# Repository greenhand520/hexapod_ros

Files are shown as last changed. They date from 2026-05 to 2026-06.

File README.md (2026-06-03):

<h1 align="center">Hexapod-ROS</h1>

<p align="center">
  <strong>一个基于 ROS2 的开源六足机器人平台，支持实时步态控制、激光雷达导航</strong>
</p>
<p align="center">
  <a href="#简介">简介</a> •
  <a href="#快速开始">快速开始</a> •
  <a href="#硬件">硬件</a> •
  <a href="#软件">软件</a> •
  <a href="#参与贡献">参与贡献</a> •
  <a href="#开源许可">开源许可</a> •
  <a href="#致谢">致谢</a>
</p>

---

## 简介

### 项目概述

Hexapod-ROS 是一个开源的六足机器人平台（目前正在利用业余时间开发中）。机器人采用双处理器架构——**鲁班猫 Zero (RK3566)** 运行 ROS2 Humble，负责高层感知、路径规划与运动控制；**STM32F405RGT6** 运行 FreeRTOS 与 MicroROS，负责实时发布 IMU 数据、充电控制、温度监控、发布电池等硬件信息。由鲁班猫直接控制的18个舵机使用的是 UBTECH 的拆机舵机，舵机详情可参考“[某宝白菜价舵机](https://gitee.com/alicedodo/xaobao_cheap_bus_servo_hack_record/)”。

**主要功能包括：**

- 18 自由度运动控制，支持逆运动学解算与多种步态模式
- 基于 360° 二维激光雷达的 SLAM 建图与自主导航（Navigation2）
- 实时 IMU 姿态估计与电池管理

<p align="center">
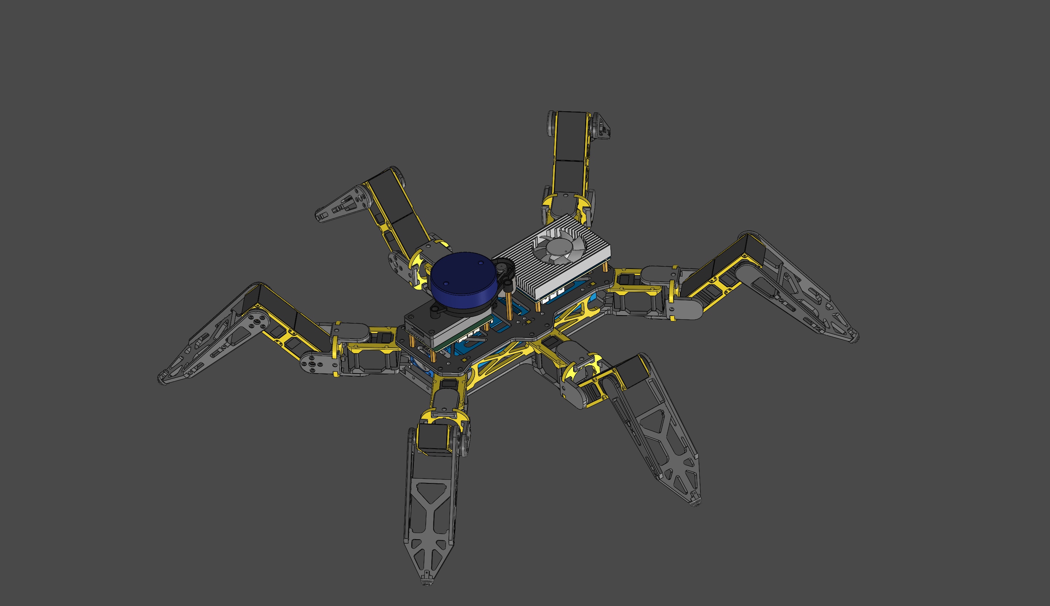
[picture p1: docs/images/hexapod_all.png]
整体结构
  
</p>

### 系统架构

系统分为三个层次：**软件层**、**硬件层**和**电源层**。以下架构图提供了完整的系统总览。

#### 硬件架构

<p align="center">
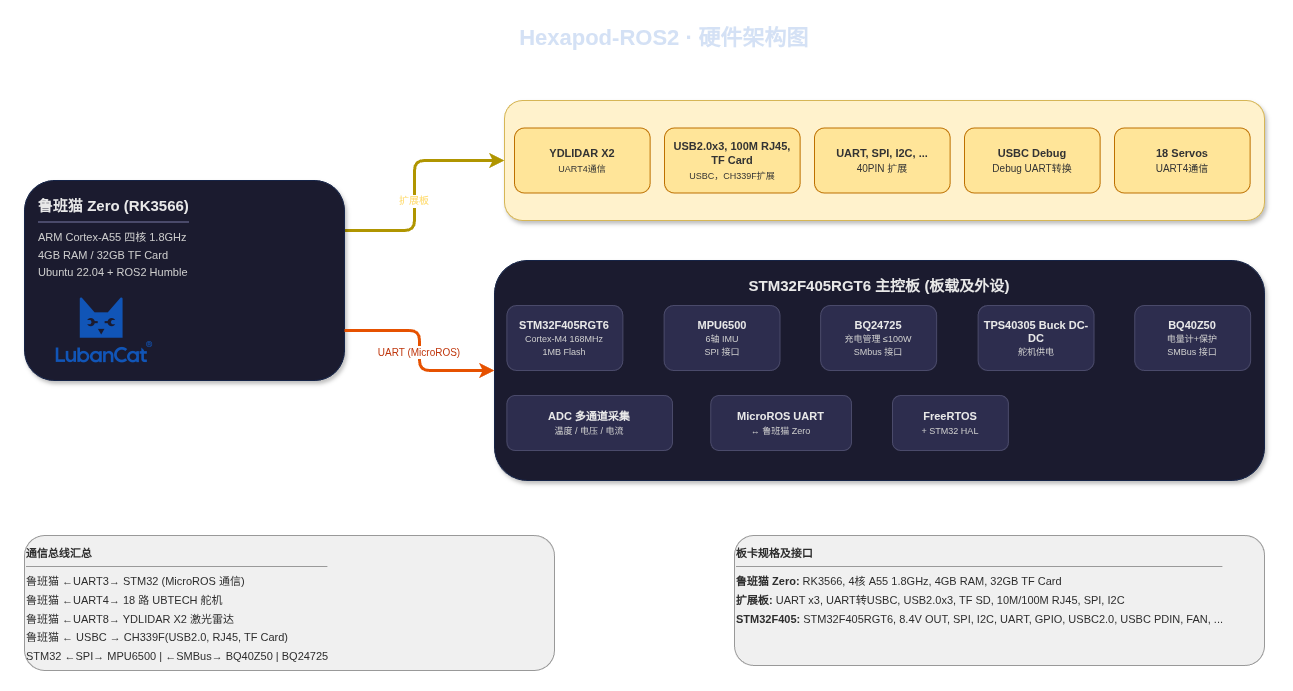
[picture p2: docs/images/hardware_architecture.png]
硬件架构图
  
</p>

> 架构图源文件位于 [`docs/diagrams/hardware_architecture.drawio`](docs/diagrams/hardware_architecture.drawio)。

#### 软件架构

TODO: 等待全部开发完毕

#### 电源架构

<p align="center">
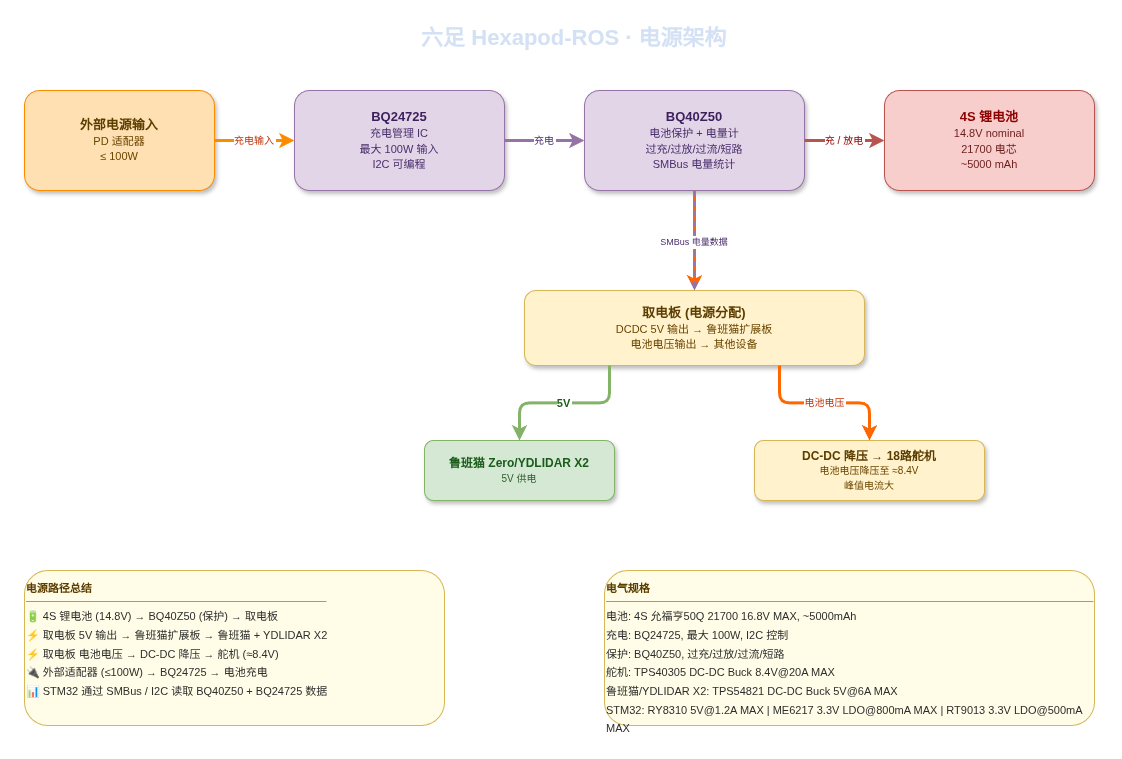
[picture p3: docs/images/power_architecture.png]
电源架构图
  
</p>

> 架构图源文件位于 [`docs/diagrams/power_architecture.drawio`](docs/diagrams/power_architecture.drawio)。

---

## 快速开始

### 环境依赖

| 组件 | 要求 |
| --- | --- |
| **操作系统（鲁班猫/开发机）** | Ubuntu 22.04 LTS |
| **开发环境** | ROS2 Humble、MicroROS for STM32、Python3.10、gcc-13、CLion、STM32CubeMX |
| **仿真环境** | Gazebo 11 |
| **3D 打印** | Bambu Lab A1、PETG 耗材（已测试） |

### 编译项目

**1. 克隆仓库**

```bash
git https://github.com/greenhand520/hexapod_ros.git
cd hexapod_ros
git submodule init   
git submodule update --remote --checkout
```

**2. 安装需要的软件包**

```bash
# YDLIDAR SDK
git clone https://github.com/YDLIDAR/YDLidar-SDK.git
cd YDLidar-SDK
mkdir build
cd build
cmake ..
make
sudo make install

# microros agent
cd software/hexapod_ros_ws/
chmod +x ./install_microros_agent.sh
./install_microros_agent.sh
```

**3. 编译 ROS2 工作空间**

```bash
cd software/hexapod_ros_ws/
rosdep install --from-paths src --ignore-src -r -y
chmod +x ./colcon_build.sh
./colcon_build.sh
source install/setup.bash
# 启动
ros2 launch hexapod_bringup start.launch.py
# 添加自启动服务
TODO
```

**4. 编译并烧录 STM32 固件**

```bash
cd software/hexapod_ros_ws/
chmod +x lib_microros_generation.sh
# 编译 microros 静态库并将相关文件复制到 hexapod_stm32f405 中
./lib_microros_generation.sh -r
```

在 Clion 中打开 `software/hexapod_stm32f405/`，编译项目后通过 ST-Link 烧录。

## 硬件

### 主控板

| 组件 | 规格 |
| --- | --- |
| **鲁班猫 Zero** | RK3566，ARM Cortex-A55 四核 1.8GHz，4GB RAM，32GB TF Card |
| **鲁班猫 Zero 扩展板** | UART ×3、UART 转 USB-C、USB2.0 ×3、TF SD、10M/100M RJ45、SPI、I2C、etc... |
| **STM32F405RGT6** | Cortex-M4 168MHz，1MB Flash，192KB SRAM，SPI、I2C、UART、GPIO、USB-C 2.0、USB-C PD 输入 |

### 外设与传感器

| 组件 | 描述 | 接口  |
| --- | --- | ----- |
| **UBTECH 舵机** ×18 | 6 条腿 × 3 关节，串口总线舵机 | UART4 |
| **YDLIDAR X2** | 二维360° 激光雷达 | UART8 |
| **MPU6500** | 6 轴 IMU（加速度计 + 陀螺仪） | SPI |
| **BQ40Z50** | 电池电量计 + 保护（过充/过放/过流/短路） | SMBus |
| **BQ24725** | 电池充电管理 IC，最大 100W 输入 | SMBus |
| **CH339F** | USB 2.0 Hub + 以太网 + TF Card 扩展 | USB-C |

### 电源系统

| 参数 | 值 |
| --- | --- |
| **电池** | 4S 锂电池（标称 14.8V），约 5000mAh，21700 电芯 |
| **充电** | BQ24725，最大 100W，SMBus 可编程 |
| **保护** | BQ40Z50，过充/过放/过流/短路保护 |
| **舵机供电** | TPS40305 Buck DC-DC，电池电压降压至约 8.4V |
| **鲁班猫供电** | 取电板 5V 输出 |
| **STM32 供电** | 3.3V LDO |

### PCB 设计

所有PCB（主控板、扩展板、取电板、电池保护版）均使用 [JLCEDA Pro](https://pro.lceda.cn/editor/) 进行设计，对应工程文件位于 [`hardware`](hardware/) 目录下。

> 最新可以直接在线查看的 PCB 项目文件可以访问 [oshwhub 发布页面](https://oshwhub.com/) （等待所有PCB测试通过）。

### 3D 打印与机械结构

机身设计参考经典 [hexapod 项目](https://github.com/SmallpTsai/hexapod-v2-7697)的结构，在参考 STL 文件后为了适配 UBTECH 舵机和 4S 21700 电池，进行了完全的重建。采用 3D 打印完成，建模参数适应 **PETG 材料** 和 **Bambu Lab A1** 打印机。其他材料和打印机未经测试，结构强度和尺寸无法保证。打印文件和物料清单（BOM）位于 [`mechanism`](mechanism/) 目录下：

```
mechanism/
├── stl/                    # 最新可打印 STL 文件
├── step/                   # STEP 文件用于生成 urdf
├── BOM.md                  # 物料清单（紧固件、轴承等）(TODO)
└── assembly_guide.md       # 装配指南(TODO)
```

> 最新打印文件访问 [Makeword 发布页面](https://makerworld.com.cn/zh)（稍后开放）。

---

##  软件

软件分为两个主要部分：**STM32 固件** 负责实时硬件驱动，**ROS2 工作空间** 运行在鲁班猫上，负责感知、规划与控制。

### STM32 固件 (`software/hexapod_stm32f405/`)

STM32 固件基于 FreeRTOS 和 STM32 HAL 库运行，通过 MicroROS 经 UART 与鲁班猫通信。

**主要职责：**

- 发布 MPU6500 的 IMU 数据（`/imu/data` 话题）
- 发布 BQ40Z50 的电池状态（`/battery/status` 话题）
- 通过 ADC 采集并发布板载温度、电压数据和BQ24725 的充电状态（`/sensor/board_state` 话题）

### ROS2 工作空间 (`software/hexapod_ros_ws/`)

ROS2 工作空间包含运行在鲁班猫 Zero（RK3566）上的所有高层功能包，系统为 Ubuntu 22.04 + ROS2 Humble。

```
software/hexapod_ros_ws/
├── src
│   ├── hexapod_bringup
│   ├── hexapod_description
│   ├── hexapod_interface
│   ├── hexapod_sensor_interface
│   ├── hexapod_test_ubtech_servo
│   ├── hexapod_test_ubtech_servo_interface
│   ├── hexapod_ubtech_ros2_control
│   └── ydlidar_ros2_driver
├── CMakeLists.txt
├── colcon_build.sh
├── env.sh
└── generate_and_deploy_microros.sh
```

#### 功能包说明

| 功能包 | 描述 |
| --- | --- |
| hexapod_bringup | 系统启动的 Launch 文件和配置。按正确顺序启动所有硬件驱动、`ros2_control` 控制器、传感器节点和 MicroROS Agent。另外包含见图、当航、IMU融合的配置和启动文件 |
| hexapod_description | RDF/Xacro 机器人模型、网格文件、TF 坐标系与 RViz 可视化配置。定义了 18 自由度运动学结构 |
| hexapod_interface | 定义了hexapod 各节点通信的 msg/service/action 文件 |
| hexapod_sensor_interface | 定义了与 stm32 通信的 msg 文件 |
| hexapod_test_ubtech_servo | 测试使用 ros2_control 控制 ubtech 舵机是否正常工作的节点 |
| hexapod_test_ubtech_servo_interface | 定义测试 ubtech 舵机服务使用的 service 文件 |
| hexapod_ubtech_ros2_control | 使用 ros2_control 控制 ubtech 舵机，后续可更换成其他舵机，只要实现对应舵机的 ros2_control功能包即可 |
| ydlidar_ros2_driver | YDLIDAR X2 激光雷达 ROS2 驱动 |
| hexapod_controller | 将速度/朝向指令转成足端轨迹/每条腿的foot trajectory，将足端轨迹 (x,y,z) 转成18个关节的舵机转动角度 |

---

## 开发进度与路线

- [x] 硬件设计（PCB、原理图）
- [x] 3D 打印机身设计（PETG、Bambu Lab A1）
- [x] 基础 ROS2 bringup 与 ros2_control
- [x] STM32 固件与 MicroROS 集成
- [x] 逆运动学解算与三角步态
- [x] YDLIDAR X2 驱动与 SLAM 集成
- [x] Navigation2 路径规划
- [ ] RL 训练环境（Gazebo + PyBullet）
- [ ] RL 运动策略训练（PPO / SAC）
- [ ] 仿真到实物策略部署
- [ ] 多步态 RL 切换（三角步态、涟漪步态、波浪步态）
- [ ] RL + Nav2 联合自主探索
- [ ] 文档与装配视频教程

---

## 参与贡献

欢迎参与贡献！请阅读以下指南：

TODO

---

## 开源许可

本项目基于 **GNU 通用公共许可证 v3.0** 开源——详见 [LICENSE](LICENSE) 文件。

硬件设计（PCB 原理图、3D 模型）基于 **CERN 开放硬件许可 v2（CERN-OHL-P-2.0）** 开源。

---

## 致谢

排名不分先后

- [ROS2](https://docs.ros.org/) — 机器人操作系统 2
- [Xiaomi MiMo Token Plan](https://platform.xiaomimimo.com/token-plan) — 小米 MiMo 大模型 Token 订阅计划
- [CLion](https://www.jetbrains.com/clion/) — 为顺畅工作流程和高效开发而设计的跨平台 C/C++ 集成开发环境
- [MicroROS](https://micro.ros.org/) — 面向微控制器的 ROS2
- [Navigation2](https://nav2.org//) — ROS2 导航框架
- [YDLIDAR](https://www.ydlidar.com/) — 激光雷达 SDK
- [鲁班猫](https://doc.embedfire.com/linux/rk356x/quick_start/zh/latest/quick_start/lubancat/lubancat.html) — 鲁班猫 Zero 单板计算机
- [JLCEDA](https://lceda.cn/) — PCB 设计工具（立创 EDA）
- [Bambu Lab](https://bambulab.com/) — 3D 打印平台

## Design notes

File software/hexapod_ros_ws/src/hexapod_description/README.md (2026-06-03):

## 新建Markdown

```xml
<joint name="coxa_L1" type="revolute">
  <limit lower="-1.047" upper="1.047" />  <!-- ±60° -->
</joint>

<joint name="femur_L1" type="revolute">
  <limit lower="-1.57" upper="0.52" />  <!-- 向下最多90°, 向上30° -->
</joint>

<joint name="tibia_L1" type="revolute">
  <limit lower="-0.52" upper="2.09" />  <!-- 弯曲范围 -->
</joint>

```

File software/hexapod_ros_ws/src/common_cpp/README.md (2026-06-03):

common_cpp

公共的日志记录，使用 spdlog 代替 rclcpp 的后端日志实现，并且支持自定义日志实现

## 使用方法

### CMakeLists配置

```cmake
find_package(common_cpp REQUIRED)

if (DEFINED ENV{CLION_IDE})
    target_link_libraries(${PROJECT_NAME} PUBLIC
            common_cpp
    )
else ()
    ament_target_dependencies(${PROJECT_NAME} PUBLIC
            common_cpp
    )
endif ()
```

### 初始化

方式1：当模块可以获取到 ros2 节点 node 实例时，可以在在 main 函数中按照下面顺序初始化全局日志

```cpp
#include "common_cpp/rclcpp_log_handler.hpp"
#include "common_cpp/spdlog_adapter.hpp"
#include "common_cpp/log_interface/log_manager.hpp"

const auto node = std::make_shared<rclcpp::Node>("log_test_node");
// 1、先使用RclcppLogHandler初始化日志logger
common_log::RclcppLogHandler::init_from_node(node);
// 2、获取刚才创建的logger实例中得到spdlogger对象
const auto logger = common_log::Logger::get_instance().get_logger();
// 3、创建一个适配spdlog的log_interface对象
const auto logger_interface = common_log::SpdlogLoggerAdapter::create_spdlog_logger(logger);
// 4、设置全局日志 这样就统一log_macro.hpp和RCLCPP_xxx()的日志记录结果了
log_interface::LogManager::set(logger_interface);
```

方式2：获取不到 node 实例时，可以按照下面顺序初始化日志

```cpp
// 还是先使用RclcppLogHandler初始化日志logger
// 假设params是你存储配置的map,map的key和yaml中定义的一样
std::unordered_map<std::string, std::string> params;
common_log::RclcppLogHandler::init_from_map(params);
// 或者自己实现获取LogConfig
LogConfig log_config;
common_log::RclcppLogHandler::init_from_config(log_config);
// 后续操作和前面一样
const auto logger = common_log::Logger::get_instance().get_logger();
const auto logger_interface = common_log::SpdlogLoggerAdapter::create_spdlog_logger(logger);
log_interface::LogManager::set(logger_interface);
```

方式3：如果不想代替 RCLCPP 的后端来记录日志，不调用`RclcppLogHandler`的几个`init_from_xxx`函数即可。

```cpp
// 先创建LogConfig，它的配置内容获取可以自己实现
common_log::LogConfig log_config;
// 这里提供了一个默认实现，假设params是你存储配置的map
std::unordered_map<std::string, std::string> params;
log_config.init_from_map(params);
// 初始化日志logger
common_log::Logger::init_from_config(&log_config);
// 后续操作和前面一样
const auto logger = common_log::Logger::get_instance().get_logger();
const auto logger_interface = common_log::SpdlogLoggerAdapter::create_spdlog_logger(logger);
log_interface::LogManager::set(logger_interface);
```

> 调用`RclcppLogHandler`中的几个`init_from_xxx`后 RCLCPP 记录日志的后端才会用这个 common_cpp 来实现，而具体的实现依靠`log_interface::LogManager::set(logger_interface);`

### 记录日志

1、ros2相关代码中正常使用

```cpp
    RCLCPP_DEBUG(node->get_logger(), "debug log test: ctcemti_log_test_node started");
    RCLCPP_INFO(node->get_logger(), "info log test: ctcemti_log_test_node started");
    RCLCPP_WARN(node->get_logger(), "warn log test: ctcemti_log_test_node started");
    RCLCPP_ERROR(node->get_logger(), "error log test: ctcemti_log_test_node started");
    RCLCPP_FATAL(node->get_logger(), "fatal log test: ctcemti_log_test_node started");
```

2、使用`log_interface/log_macro.hpp`中的宏

```cpp
LOG_DEBUG("test_log_debug {}", 123);
LOG_INFO("test_log_info {}", 123);
LOG_INFO("Joint '{}' (ID {}): initial {:.1f}° → {:.4f} rad", jd.name, jd.servo_id, sa.actual_deg, pos);
LOG_WARN("test_log_warn {}", 123);
LOG_ERROR("test_log_error {}", 123);
LOG_FATAL("test_log_fatal {}", 123);
```

### 参数配置

`common_log::RclcppLogHandler::init_from_node(node);`会从 node 的参数中获取一些日志相关的配置，如下：

```yaml
log:
    # 日志登记
    log_level: debug
    # 日志路径
    log_path: ./log
    # 是否是异步日志
    async: false
    # 日志器名字，会影响最终日志文件的名字，不设置的话默认使用节点名
    logger_nama: test
```

上面配置最终会产生日志的路径是`./log/log_test.log`

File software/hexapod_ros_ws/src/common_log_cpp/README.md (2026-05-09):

common_log_cpp

公共的日志记录，使用 spdlog 代替 rclcpp 的后端日志实现，并且支持自定义日志实现

## 使用方法

### CMakeLists配置

```cmake
find_package(common_log_cpp REQUIRED)

if (DEFINED ENV{CLION_IDE})
    target_link_libraries(${PROJECT_NAME} PUBLIC
            common_log_cpp
    )
else ()
    ament_target_dependencies(${PROJECT_NAME} PUBLIC
            common_log_cpp
    )
endif ()
```

### 初始化

方式1：当模块可以获取到 ros2 节点 node 实例时，可以在在 main 函数中按照下面顺序初始化全局日志

```cpp
#include "common_log_cpp/rclcpp_log_handler.hpp"
#include "common_log_cpp/spdlog_adapter.hpp"
#include "common_log_cpp/log_interface/log_manager.hpp"

const auto node = std::make_shared<rclcpp::Node>("log_test_node");
// 1、先使用RclcppLogHandler初始化日志logger
common_log::RclcppLogHandler::init_from_node(node);
// 2、获取刚才创建的logger实例中得到spdlogger对象
const auto logger = common_log::Logger::get_instance().get_logger();
// 3、创建一个适配spdlog的log_interface对象
const auto logger_interface = common_log::SpdlogLoggerAdapter::create_spdlog_logger(logger);
// 4、设置全局日志 这样就统一log_macro.hpp和RCLCPP_xxx()的日志记录结果了
log_interface::LogManager::set(logger_interface);
```

方式2：获取不到 node 实例时，可以按照下面顺序初始化日志

```cpp
// 还是先使用RclcppLogHandler初始化日志logger
// 假设params是你存储配置的map,map的key和yaml中定义的一样
std::unordered_map<std::string, std::string> params;
common_log::RclcppLogHandler::init_from_map(params);
// 或者自己实现获取LogConfig
LogConfig log_config;
common_log::RclcppLogHandler::init_from_config(log_config);
// 后续操作和前面一样
const auto logger = common_log::Logger::get_instance().get_logger();
const auto logger_interface = common_log::SpdlogLoggerAdapter::create_spdlog_logger(logger);
log_interface::LogManager::set(logger_interface);
```

方式3：如果不想代替 RCLCPP 的后端来记录日志，不调用`RclcppLogHandler`的几个`init_from_xxx`函数即可。

```cpp
// 先创建LogConfig，它的配置内容获取可以自己实现
common_log::LogConfig log_config;
// 这里提供了一个默认实现，假设params是你存储配置的map
std::unordered_map<std::string, std::string> params;
log_config.init_from_map(params);
// 初始化日志logger
common_log::Logger::init_from_config(&log_config);
// 后续操作和前面一样
const auto logger = common_log::Logger::get_instance().get_logger();
const auto logger_interface = common_log::SpdlogLoggerAdapter::create_spdlog_logger(logger);
log_interface::LogManager::set(logger_interface);
```

> 调用`RclcppLogHandler`中的几个`init_from_xxx`后 RCLCPP 记录日志的后端才会用这个 common_log_cpp 来实现，而具体的实现依靠`log_interface::LogManager::set(logger_interface);`

### 记录日志

1、ros2相关代码中正常使用

```cpp
    RCLCPP_DEBUG(node->get_logger(), "debug log test: ctcemti_log_test_node started");
    RCLCPP_INFO(node->get_logger(), "info log test: ctcemti_log_test_node started");
    RCLCPP_WARN(node->get_logger(), "warn log test: ctcemti_log_test_node started");
    RCLCPP_ERROR(node->get_logger(), "error log test: ctcemti_log_test_node started");
    RCLCPP_FATAL(node->get_logger(), "fatal log test: ctcemti_log_test_node started");
```

2、使用`log_interface/log_macro.hpp`中的宏

```cpp
LOG_DEBUG("test_log_debug {}", 123);
LOG_INFO("test_log_info {}", 123);
LOG_INFO("Joint '{}' (ID {}): initial {:.1f}° → {:.4f} rad", jd.name, jd.servo_id, sa.actual_deg, pos);
LOG_WARN("test_log_warn {}", 123);
LOG_ERROR("test_log_error {}", 123);
LOG_FATAL("test_log_fatal {}", 123);
```

### 参数配置

`common_log::RclcppLogHandler::init_from_node(node);`会从 node 的参数中获取一些日志相关的配置，如下：

```yaml
log:
    # 日志登记
    log_level: debug
    # 日志路径
    log_path: ./log
    # 是否是异步日志
    async: false
    # 日志器名字，会影响最终日志文件的名字，不设置的话默认使用节点名
    logger_nama: test
```

上面配置最终会产生日志的路径是`./log/log_test.log`

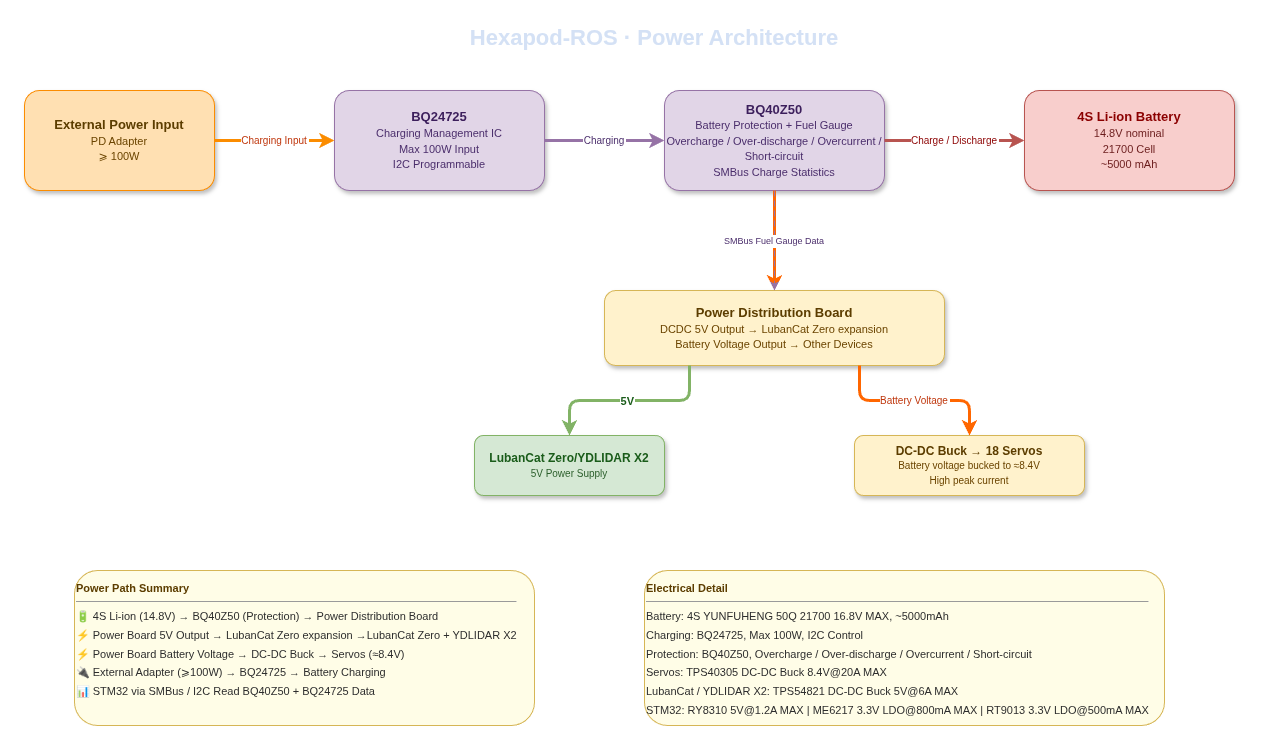
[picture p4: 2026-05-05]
docs/images/power_architecture_en.png

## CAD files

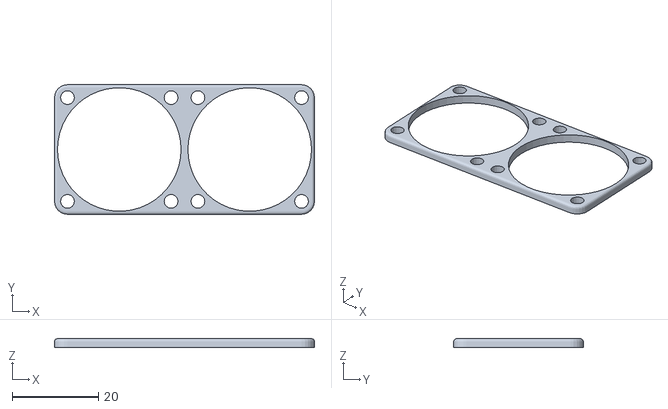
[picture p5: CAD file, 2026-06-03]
mechanism/stl/3010_fan_bracket_full.stl
60.2 x 30.0 x 2.00

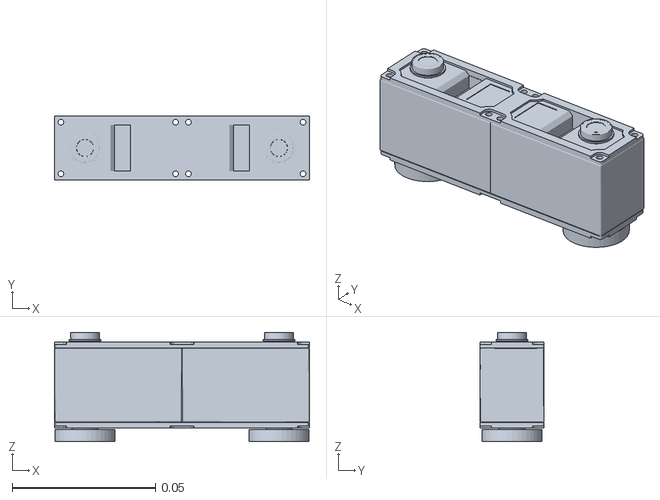
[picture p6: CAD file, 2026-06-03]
software/hexapod_ros_ws/src/hexapod_description/meshes/femur1_link.STL
0.089 x 0.0225 x 0.0381

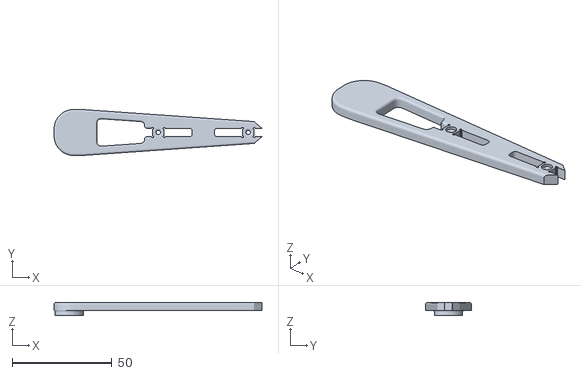
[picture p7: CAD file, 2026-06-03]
mechanism/stl/tibia_bearing.stl
104.5 x 23.2 x 6.60

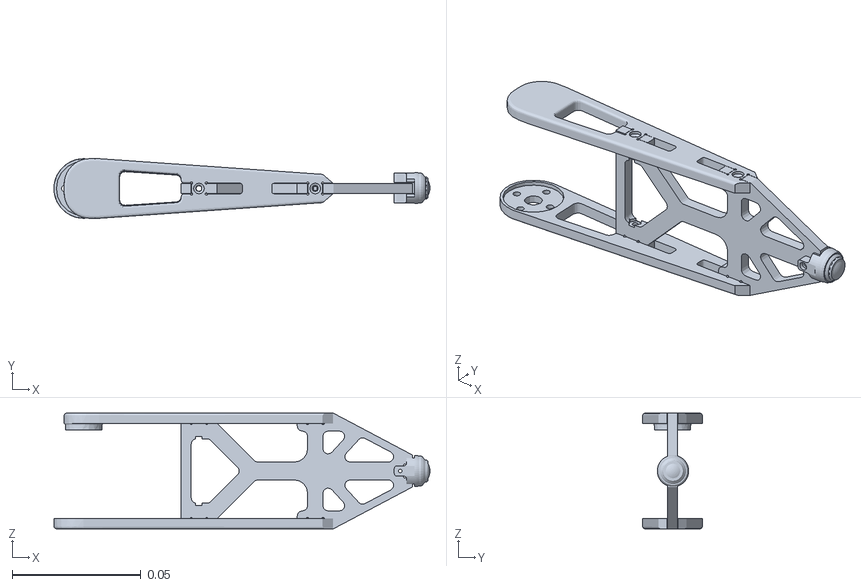
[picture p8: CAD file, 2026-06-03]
software/hexapod_ros_ws/src/hexapod_description/meshes/tibia3_link.STL
0.146 x 0.0232 x 0.045

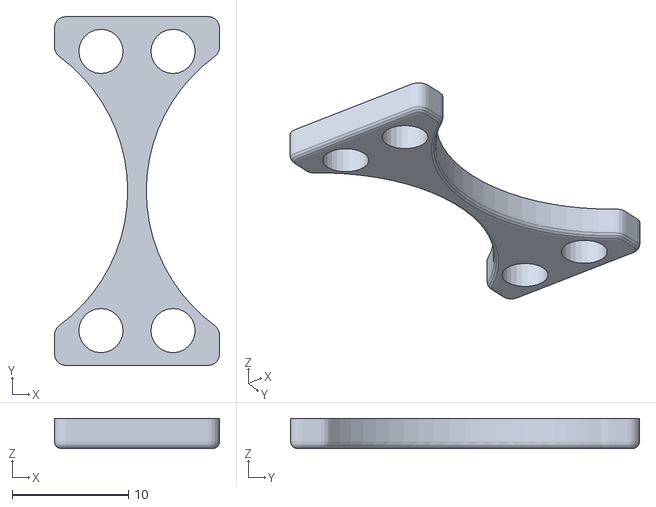
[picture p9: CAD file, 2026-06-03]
mechanism/stl/3010_fan_bracket.stl
14.2 x 30.0 x 2.60

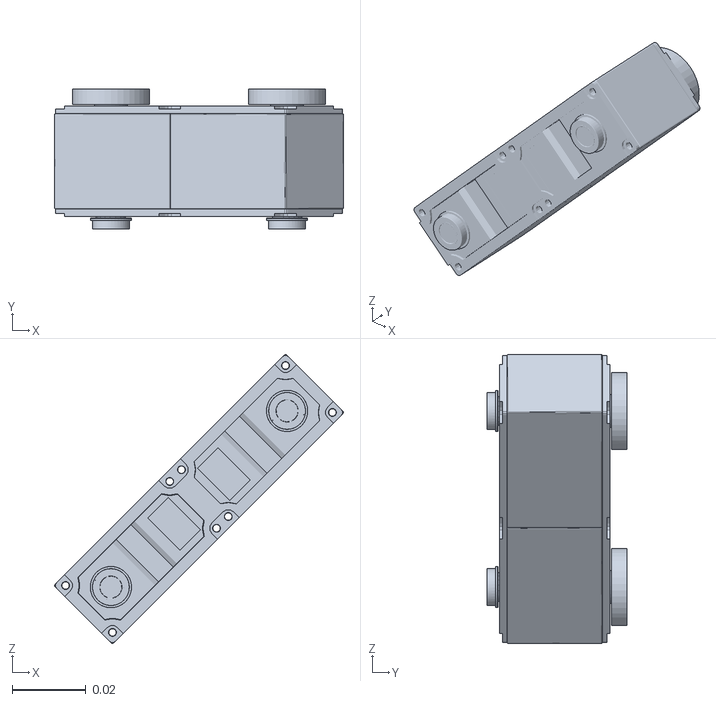
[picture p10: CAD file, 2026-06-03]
software/hexapod_ros_ws/src/hexapod_description/meshes/femur5_link.STL
0.0785 x 0.0381 x 0.0785

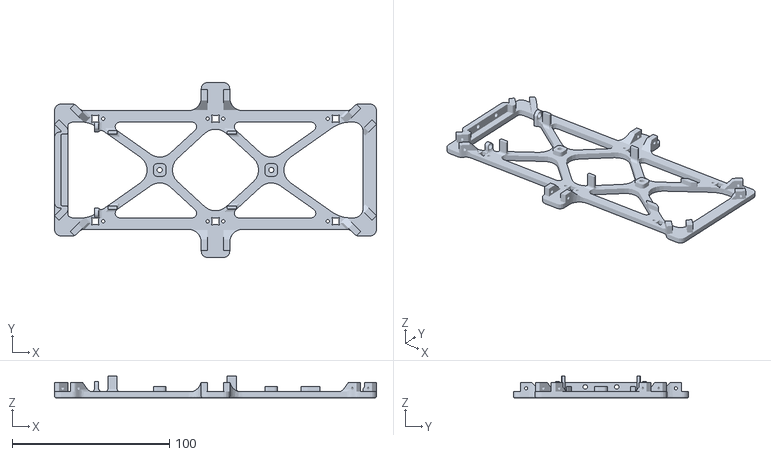
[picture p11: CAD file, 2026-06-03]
mechanism/stl/body_bottom.stl
205.0 x 111.5 x 14.0

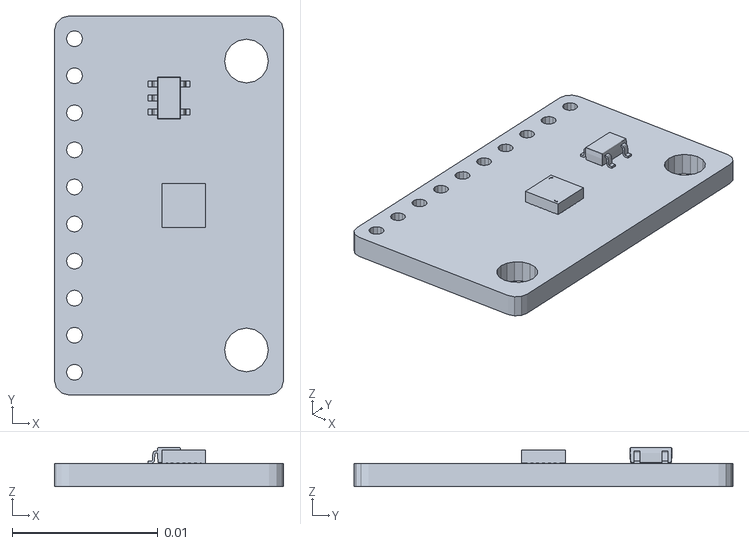
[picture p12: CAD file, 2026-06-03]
software/hexapod_ros_ws/src/hexapod_description/meshes/imu_link.STL
0.0157 x 0.026 x 0.0027

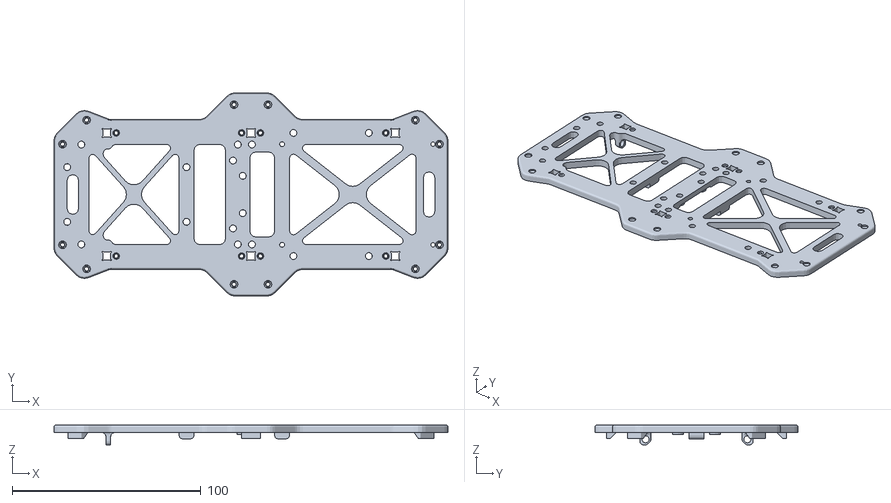
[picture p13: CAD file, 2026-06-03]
mechanism/stl/body_top.stl
209.0 x 107.7 x 10.6

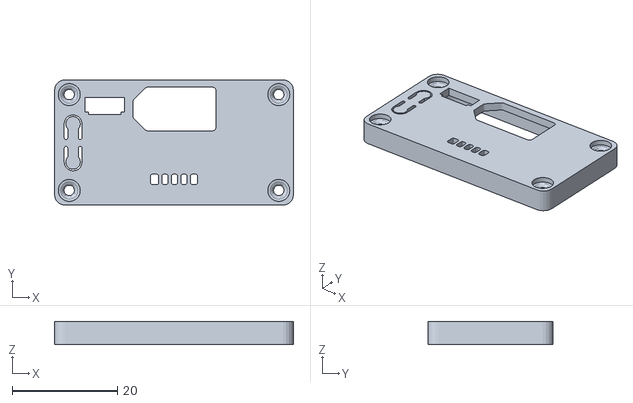
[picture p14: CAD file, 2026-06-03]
mechanism/stl/BZ40Z50_cover.stl
45.4 x 23.8 x 4.40

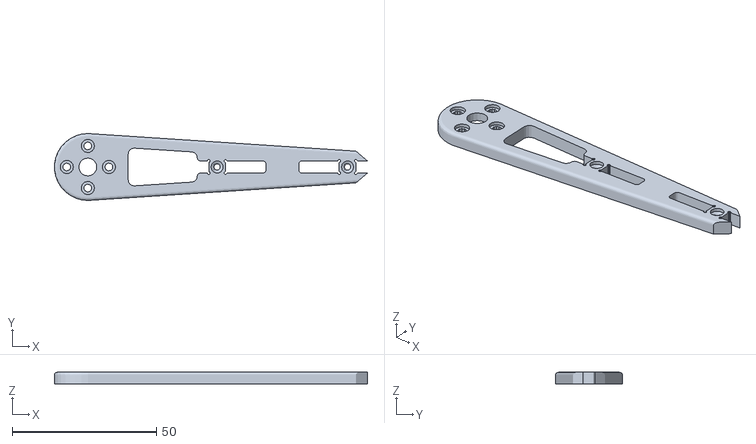
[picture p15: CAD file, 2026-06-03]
mechanism/stl/tibia_flange.stl
108.5 x 23.2 x 4.00

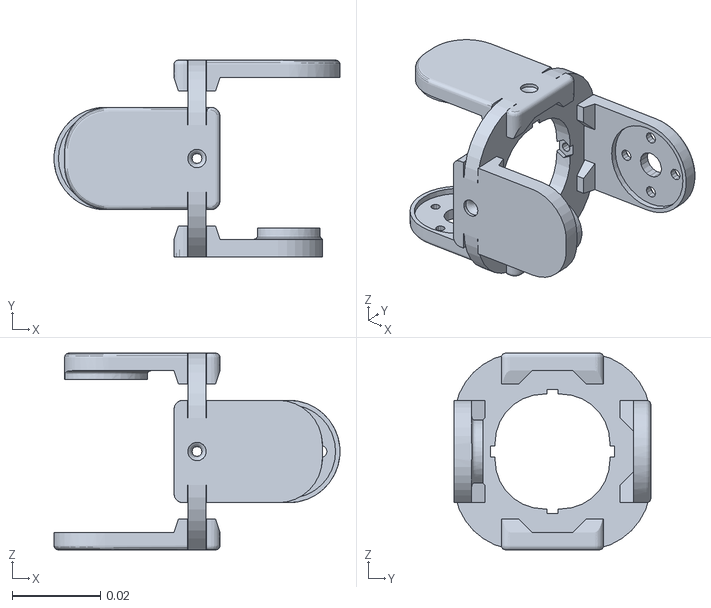
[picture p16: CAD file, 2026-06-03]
software/hexapod_ros_ws/src/hexapod_description/meshes/coxa5_link.STL
0.0648 x 0.0446 x 0.0446

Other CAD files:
mechanism/solidworks/hexapod.SLDASM
software/hexapod_ros_ws/src/hexapod_description/meshes/femur6_link.STL
software/hexapod_ros_ws/src/hexapod_description/meshes/femur4_link.STL
software/hexapod_ros_ws/src/hexapod_description/meshes/femur2_link.STL
software/hexapod_ros_ws/src/hexapod_description/meshes/femur3_link.STL
software/hexapod_ros_ws/src/hexapod_description/meshes/tibia4_link.STL
mechanism/stl/21700_battery_holder_bottom.stl
mechanism/stl/21700_battery_holder_bottom_cover.stl
mechanism/stl/21700_battery_holder_cover.stl
mechanism/stl/21700_battery_holder_top.stl
mechanism/stl/body_side.stl
mechanism/stl/coxa_bottom.stl
mechanism/stl/coxa_femur_joint_cross.stl
mechanism/stl/coxa_joint_bearing.stl
mechanism/stl/coxa_joint_flange.stl
mechanism/stl/coxa_top.stl
mechanism/stl/femur.stl
mechanism/stl/femur_joint_bearing.stl
mechanism/stl/femur_joint_flange.stl
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

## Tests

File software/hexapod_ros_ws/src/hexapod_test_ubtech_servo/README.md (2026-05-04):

# hexapod_test_ubtech_servo

## 简介

这个功能包是用来测试`hexapod_ubtech_ros2_control`中对 UBTECH 串口舵机协议的实现。节点名是`hexapod_test_ubtech_servo_node`，对应的可执行文件是`hexapod_test_ubtech_servo_exe`。

## 启动

1、控制台启动

```bash
# 使用config下的hexapod_test_ubtech_servo_node.yaml配置文件
ros2 launch hexapod_test_ubtech_servo start_node.launch.py

# 或者使用覆盖参数
ros2 launch hexapod_test_ubtech_servo start_node.launch.py \
    serial_device:=/dev/ttyAMA0 \
    baud_rate:=9600 \
    tx_en_line:=17

```

2、在别的 Launch 文件中被调用

```python
# robot_bringup/launch/robot.launch.py

debug_node = IncludeLaunchDescription(
    PythonLaunchDescriptionSource(
        PathJoinSubstitution([
            FindPackageShare('hexapod_test_ubtech_servo'),
            'launch', 'start_node.launch.py'
        ])
    ),
    launch_arguments={
        # 指向 bringup 包自己的配置文件
        'config_file': PathJoinSubstitution([
            FindPackageShare('robot_bringup'),
            'config', 'hexapod_test_ubtech_servo_node.yaml'
        ]),
    }.items(),
)
```

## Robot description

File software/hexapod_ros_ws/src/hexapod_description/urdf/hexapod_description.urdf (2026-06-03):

<?xml version="1.0" encoding="utf-8"?>
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
<robot name="hexapod_description">
  <link name="base_link">
    <inertial>
      <origin xyz="-0.000541355821538692 -0.000113244311722492 0.00631855141572124" rpy="0 0 0" />
      <mass value="0.528835123133918" />
      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
    </inertial>
    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
  </link>
  <link name="laser_frame">
    <inertial>
      <origin xyz="0.0127016129333694 -1.24853520894596E-05 -0.0157088713483309" rpy="0 0 0" />
      <mass value="0.0387549710715716" />
      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
    </inertial>
    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
  </link>
  <joint name="lidar_joint" type="fixed">
    <origin xyz="0.0455500000000008 0 0.07635" rpy="0 0 3.14159265358979" />
    <parent link="base_link" />
    <child link="laser_frame" />
    <axis xyz="0 0 0" />
  </joint>
  <link name="imu_link">
    <inertial>
      <origin xyz="-0.00103689884799777 5.92360608713816E-05 -0.00122236223464343" rpy="0 0 0" />
      <mass value="0.000627032096889045" />
      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
    </inertial>
    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
  </link>
  <joint name="imu_joint" type="fixed">
    <origin xyz="0.000105993141985894 0 0.01505" rpy="0 0 0" />
    <parent link="base_link" />
    <child link="imu_link" />
    <axis xyz="0 0 0" />
  </joint>
  <link name="coxa1_link">
    <inertial>
      <origin xyz="0.0209415537659286 -0.000684770999468062 0.0228008660035498" rpy="0 0 0" />
      <mass value="0.0149522376369557" />
      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
    </inertial>
    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
  </link>
  <joint name="coxa1_joint" type="revolute">
    <origin xyz="0.121195903294573 0.060665246712167 -0.0221499999999985" rpy="0 0 0.748071247328702" />
    <parent link="base_link" />
    <child link="coxa1_link" />
    <axis xyz="0 0 -1" />
    <limit lower="-1.0472" upper="1.0472" effort="0" velocity="0" />
  </joint>
  <link name="femur1_link">
    <inertial>
      <origin xyz="0.0338552747728894 -7.7715611723761E-16 0.0214450718735523" rpy="0 0 0" />
      <mass value="0.0594309738157123" />
      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
    </inertial>
    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
  </link>
  <joint name="femur1_joint" type="revolute">
    <origin xyz="0.0416 0.0223000000000001 0.0223" rpy="1.57079632679496 -0.785398163397445 0" />
    <parent link="coxa1_link" />
    <child link="femur1_link" />
    <axis xyz="0 0 1" />
    <limit lower="-2.3562" upper="0.7854" effort="0" velocity="0" />
  </joint>
  <link name="tibia1_link">
    <inertial>
      <origin xyz="0.0590007960502528 1.17541643132046E-05 0.0231485958132373" rpy="0 0 0" />
      <mass value="0.0177903764535732" />
      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
    </inertial>
    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
  </link>
  <joint name="tibia1_joint" type="revolute">
    <origin xyz="0.0676800000000025 0 0" rpy="0 0 -1.5707963267949" />
    <parent link="femur1_link" />
    <child link="tibia1_link" />
    <axis xyz="0 0 -1" />
    <limit lower="-2.09" upper="1.06" effort="0" velocity="0" />
  </joint>
  <link name="coxa2_link">
    <inertial>
      <origin xyz="0.020942 -0.00068477 0.022801" rpy="0 0 0" />
      <mass value="0.014952" />
      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
    </inertial>
    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
  </link>
  <joint name="coxa2_joint" type="revolute">
    <origin xyz="0 0.0866973593128809 -0.0221499999999984" rpy="0 0 1.53346941072615" />
    <parent link="base_link" />
    <child link="coxa2_link" />
    <axis xyz="0 0 -1" />
    <limit lower="-1.0472" upper="1.0472" effort="0" velocity="0" />
  </joint>
  <link name="femur2_link">
    <inertial>
      <origin xyz="0.033855 6.266E-13 0.021445" rpy="0 0 0" />
      <mass value="0.059431" />
      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
    </inertial>
    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
  </link>
  <joint name="femur2_joint" type="revolute">
    <origin xyz="0.0416000000000027 0.0222999999999845 0.0223000000000167" rpy="1.57079632679586 -0.785398163397445 0" />
    <parent link="coxa2_link" />
    <child link="femur2_link" />
    <axis xyz="0 0 -1" />
    <limit lower="-2.3562" upper="0.7854" effort="0" velocity="0" />
  </joint>
  <link name="tibia2_link">
    <inertial>
      <origin xyz="0.059001 1.1755E-05 0.023149" rpy="0 0 0" />
      <mass value="0.01779" />
      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
    </inertial>
    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
  </link>
  <joint name="tibia2_joint" type="revolute">
    <origin xyz="0.0676799999999998 0 0" rpy="0 0 -1.5707963267949" />
    <parent link="femur2_link" />
    <child link="tibia2_link" />
    <axis xyz="0 0 -1" />
    <limit lower="-2.09" upper="1.06" effort="0" velocity="0" />
  </joint>
  <link name="coxa3_link">
    <inertial>
      <origin xyz="0.020942 -0.00068477 0.022801" rpy="0 0 0" />
      <mass value="0.014952" />
      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
    </inertial>
    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
  </link>
  <joint name="coxa3_joint" type="revolute">
    <origin xyz="-0.121165246712168 0.0606959032945723 -0.0221499999999985" rpy="0 0 2.3188675741236" />
    <parent link="base_link" />
    <child link="coxa3_link" />
    <axis xyz="0 0 -1" />
    <limit lower="-1.0472" upper="1.0472" effort="0" velocity="0" />
  </joint>
  <link name="femur3_link">
    <inertial>
      <origin xyz="0.033855 -6.6613E-16 0.021445" rpy="0 0 0" />
      <mass value="0.059431" />
      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
    </inertial>
    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
  </link>
  <joint name="femur3_joint" type="revolute">
    <origin xyz="0.0416000000000026 0.0222999999999987 0.0223000000000024" rpy="1.57079632679496 -0.785398163397445 0" />
    <parent link="coxa3_link" />
    <child link="femur3_link" />
    <axis xyz="0 0 -1" />
    <limit lower="-2.3562" upper="0.7854" effort="0" velocity="0" />
  </joint>
  <link name="tibia3_link">
    <inertial>
      <origin xyz="0.059001 1.1754E-05 0.023149" rpy="0 0 0" />
      <mass value="0.01779" />
      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
    </inertial>
    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
  </link>
  <joint name="tibia3_joint" type="revolute">
    <origin xyz="0.0676799999999997 0 0" rpy="0 0 -1.5707963267949" />
    <parent link="femur3_link" />
    <child link="tibia3_link" />
    <axis xyz="0 0 -1" />
    <limit lower="-2.09" upper="1.06" effort="0" velocity="0" />
  </joint>
  <link name="coxa4_link">
    <inertial>
      <origin xyz="0.0209415537659286 -0.000684770999469175 0.0228008660035498" rpy="0 0 0" />
      <mass value="0.0149522376369557" />
      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
    </inertial>
    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
  </link>
  <joint name="coxa4_joint" type="revolute">
    <origin xyz="0.121195903294573 -0.0606652467121672 -0.022149999999999" rpy="0 0 -0.822725079466195" />
    <parent link="base_link" />
    <child link="coxa4_link" />
    <axis xyz="0 0 -1" />
    <limit lower="-1.0472" upper="1.0472" effort="0" velocity="0" />
  </joint>
  <link name="femur4_link">
    <inertial>
      <origin xyz="0.0338552747728859 -6.80011602582908E-16 0.0214450718735523" rpy="0 0 0" />
      <mass value="0.0594309738157123" />
      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
    </inertial>
    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
  </link>
  <joint name="femur4_joint" type="revolute">
    <origin xyz="0.0416000000000027 0.0222999999999989 0.0223000000000022" rpy="1.57079632679494 -0.785398163397445 0" />
    <parent link="coxa4_link" />
    <child link="femur4_link" />
    <axis xyz="0 0 -1" />
    <limit lower="-2.3562" upper="0.7854" effort="0" velocity="0" />
  </joint>
  <link name="tibia4_link">
    <inertial>
      <origin xyz="0.0590007960502643 1.17541643124275E-05 0.0231485958132372" rpy="0 0 0" />
      <mass value="0.0177903764535731" />
      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
    </inertial>
    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
  </link>
  <joint name="tibia4_joint" type="revolute">
    <origin xyz="0.0676799999999997 0 0" rpy="0 0 -1.5707963267949" />
    <parent link="femur4_link" />
    <child link="tibia4_link" />
    <axis xyz="0 0 -1" />
    <limit lower="-2.09" upper="1.06" effort="0" velocity="0" />
  </joint>
  <link name="coxa5_link">
    <inertial>
      <origin xyz="0.0209415515934279 -0.000684771371421158 0.0228008700808051" rpy="0 0 0" />
      <mass value="0.0149522392497564" />
      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
    </inertial>
    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
  </link>
  <joint name="coxa5_joint" type="revolute">
    <origin xyz="0 -0.0866973593128807 -0.022149999999999" rpy="0 0 -1.60812324286364" />
    <parent link="base_link" />
    <child link="coxa5_link" />
    <axis xyz="0 0 -1" />
    <limit lower="-1.0472" upper="1.0472" effort="0" velocity="0" />
  </joint>
  <link name="femur5_link">
    <inertial>
      <origin xyz="0.0655392943707835 0.000854928128865985 0.046239294371669" rpy="0 0 0" />
      <mass value="0.0594309738157718" />
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

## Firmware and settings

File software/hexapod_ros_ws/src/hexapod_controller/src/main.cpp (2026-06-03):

//
// Created by greenhand520 on 2026/5/4.
//

#include <rclcpp/rclcpp.hpp>

#include "common_cpp/log/log_interface/log_manager.hpp"
#include "common_cpp/log/rclcpp_log_handler.hpp"
#include "common_cpp/log/spdlog_adapter.hpp"

int main(int argc, char* argv[]) {
    rclcpp::init(argc, argv);
    const auto node = std::make_shared<rclcpp::Node>("hexapod_controller_node");

    common_log::RclcppLogHandler::init_from_node(node);
    const auto logger = common_log::Logger::get_instance().get_logger();
    const auto logger_interface = common_log::SpdlogLoggerAdapter::create_spdlog_logger(logger, node);
    log_interface::LogManager::set(logger_interface);

    rclcpp::spin(node);
    rclcpp::shutdown();
    return 0;
}

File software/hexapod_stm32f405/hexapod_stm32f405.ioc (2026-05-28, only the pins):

Mcu.UserName=STM32F405RGTx
PA10.GPIO_Label=BUZZ
PA10.Signal=S_TIM1_CH3
PA11.Signal=USB_OTG_FS_DM
PA12.Signal=USB_OTG_FS_DP
PA13.Signal=SYS_JTMS-SWDIO
PA14.Signal=SYS_JTCK-SWCLK
PA2.Signal=USART2_TX
PA3.Signal=USART2_RX
PA4.GPIO_Label=CS1_MPU
PA4.Signal=GPIO_Output
PA5.Signal=SPI1_SCK
PA6.Signal=SPI1_MISO
PA7.Signal=SPI1_MOSI
PA9.Signal=USB_OTG_FS_VBUS
PB10.Signal=I2C2_SCL
PB11.Signal=I2C2_SDA
PB2.GPIO_Label=HUSB238A_INT
PB2.Signal=GPXTI2
PB7.GPIO_Label=WS2812
PB7.Signal=S_TIM4_CH2
PB8.Signal=I2C1_SCL
PB9.Signal=I2C1_SDA
PC0.GPIO_Label=BC_IOUT
PC0.Signal=ADCx_IN10
PC1.GPIO_Label=TEMP1_ADC
PC1.Signal=ADCx_IN11
PC12.Signal=UART5_TX
PC13-ANTI_TAMP.GPIO_Label=VM_EN
PC13-ANTI_TAMP.Signal=GPIO_Output
PC14-OSC32_IN.GPIO_Label=AC_OK
PC14-OSC32_IN.Signal=GPXTI14
PC15-OSC32_OUT.GPIO_Label=MPU_INT
PC15-OSC32_OUT.Signal=GPXTI15
PC2.GPIO_Label=TEMP2_ADC
PC2.Signal=ADCx_IN12
PC3.GPIO_Label=SVM_ADC
PC3.Signal=ADCx_IN13
PC4.GPIO_Label=FAN_EN
PC4.Signal=GPIO_Output
PC5.GPIO_Label=CV_ADC
PC5.Signal=ADCx_IN15
PD2.Signal=UART5_RX
PH0-OSC_IN.Signal=RCC_OSC_IN
PH1-OSC_OUT.Signal=RCC_OSC_OUT

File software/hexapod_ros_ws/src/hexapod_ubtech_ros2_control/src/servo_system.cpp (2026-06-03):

//
// Created by greenhand520 on 2026/4/25.
//


#include <hardware_interface/types/hardware_interface_type_values.hpp>
#include <pluginlib/class_list_macros.hpp>

#include <chrono>
#include <cmath>
#include <fcntl.h>
#include <string>
#include <vector>

#include "hexapod_ubtech_ros2_control/servo_system.hpp"

#include "common_cpp/log/log.hpp"
#include "common_cpp/log/log_interface/log_macro.hpp"
#include "common_cpp/log/log_interface/log_manager.hpp"
#include "common_cpp/log/rclcpp_log_handler.hpp"
#include "common_cpp/log/spdlog_adapter.hpp"
#include "hexapod_ubtech_ros2_control/ubtech_servo.hpp"

namespace ubtech_servo_hardware {

    hardware_interface::CallbackReturn UbtechServoSystem::on_init(const hardware_interface::HardwareInfo& info) {
        if (SystemInterface::on_init(info) !=
            hardware_interface::CallbackReturn::SUCCESS) {
            return hardware_interface::CallbackReturn::ERROR;
        }

        // Hardware-level parameters
        const auto& params = info_.hardware_parameters;

        common_log::RclcppLogHandler::init_from_map(params);
        const auto logger = common_log::Logger::get_instance().get_logger();
        const auto logger_interface = common_log::SpdlogLoggerAdapter::create_spdlog_logger(logger);
        log_interface::LogManager::set(logger_interface);

        serial_device_ = params.contains("serial_device") ? params.at("serial_device") : "/dev/ttyS4";
        baud_rate_ = params.contains("baud_rate") ? std::stoi(params.at("baud_rate")) : 115200;
        gpio_name_ = params.contains("gpio_name") ? params.at("gpio_name") : "GPIO1_B1";

        // ── Per-joint parameters ──
        joints_.resize(info_.joints.size());

        for (size_t i = 0; i < info_.joints.size(); ++i) {
            const auto& joint_info = info_.joints[i];
            auto& [name, servo_id, angle_offset_deg, pos_state, vel_state, pos_cmd, prev_pos_state] = joints_[i];

            name = joint_info.name;

            // servo_id is mandatory
            if (!joint_info.parameters.contains("servo_id")) {
                LOG_ERROR("Joint '{}': missing required parameter 'servo_id'", name)
                return hardware_interface::CallbackReturn::ERROR;
            }
            servo_id = static_cast<uint8_t>(std::stoi(joint_info.parameters.at("servo_id")));

            pos_state = 0.0;
            vel_state = 0.0;
            pos_cmd = 0.0;
            prev_pos_state = 0.0;

            // Validate interfaces
            bool has_pos_cmd = false;
            for (const auto& ci : joint_info.command_interfaces) {
                if (ci.name == hardware_interface::HW_IF_POSITION)
                    has_pos_cmd = true;
            }
            if (!has_pos_cmd) {
                LOG_ERROR("Joint '{}': needs a 'position' command interface", name);
                return hardware_interface::CallbackReturn::ERROR;
            }
        }
        
        LOG_INFO("on_init: {} joint(s), serial={} @ {} baud, gpio={}",
                    joints_.size(), serial_device_, baud_rate_, gpio_name_);

        return hardware_interface::CallbackReturn::SUCCESS;
    }

    /// @brief on_configure — open serial port, configure GPIO
    hardware_interface::CallbackReturn UbtechServoSystem::on_configure(
        const rclcpp_lifecycle::State& /*prev*/) {
        // Serial
        serial_ = std::make_unique<lubancat_hw::SerialPort>();
        if (!serial_->open(serial_device_, baud_rate_)) {
            LOG_ERROR("Cannot open serial port '%s' at %d baud", serial_device_, baud_rate_);
            return hardware_interface::CallbackReturn::ERROR;
        }

        // GPIO TX_EN
        tx_en_ = std::make_unique<lubancat_hw::GpioPin>();
        if (!tx_en_->open(gpio_name_, "ubtech_servo_tx_en")) {
            LOG_ERROR("Cannot open GPIO %s", gpio_name_);
            return hardware_interface::CallbackReturn::ERROR;
        }

        // Servo controller
        servo_ = std::make_unique<UbtechServo>(serial_.get(), tx_en_.get());

        LOG_INFO("on_configure: success");
        return hardware_interface::CallbackReturn::SUCCESS;
    }


    /// @brief on_activate — read initial positions
    hardware_interface::CallbackReturn UbtechServoSystem::on_activate(
        const rclcpp_lifecycle::State& /*prev*/) {
        for (auto& jd : joints_) {
            ServoAngle angle{};
            if (auto result = servo_->read_angle(jd.servo_id, angle); result.has_value() && result.value()) {
                // actual_rad already accounts for the 120° servo center offset
                const double pos = angle.actual_rad + jd.angle_offset_deg * DEG2RAD;
                jd.pos_state = pos;
                jd.prev_pos_state = pos;
                jd.pos_cmd = pos;

                LOG_INFO("Joint '{}' (ID {}): initial {:.4f} rad",
                            jd.name, jd.servo_id, pos);
            }
            else {
                const std::string err = result.has_value() ? "unknown error" : result.error();
                LOG_WARN("Joint '{}' (ID {}): failed to read initial angle: {}",
                            jd.name, jd.servo_id, err);
            }
        }

        return hardware_interface::CallbackReturn::SUCCESS;
    }

    ///@brief on_deactivate — stop all servos
    hardware_interface::CallbackReturn UbtechServoSystem::on_deactivate(
        const rclcpp_lifecycle::State& /*prev*/) {
        for (const auto& jd : joints_) {
            if (auto result = servo_->stop(jd.servo_id); !result.has_value()) {
                LOG_WARN("Joint '{}' (ID {}): stop failed: {}",
                            jd.name, jd.servo_id, result.error());
            }
            else if (!result.value()) {
                LOG_WARN("Joint '{}' (ID {}): stop returned false",
                            jd.name, jd.servo_id);
            }
        }
        LOG_INFO("on_deactivate: servos stopped");
        return hardware_interface::CallbackReturn::SUCCESS;
    }

    /// @brief on_cleanup — release resources
    hardware_interface::CallbackReturn UbtechServoSystem::on_cleanup(
        const rclcpp_lifecycle::State& /*prev*/) {
        servo_.reset();
        tx_en_.reset();
        serial_.reset();
        LOG_INFO("on_cleanup: done");
        return hardware_interface::CallbackReturn::SUCCESS;
    }

    std::vector<hardware_interface::StateInterface> UbtechServoSystem::export_state_interfaces() {
        std::vector<hardware_interface::StateInterface> si;
        si.reserve(joints_.size() * 2);

        for (auto& jd : joints_) {
            si.emplace_back(jd.name, hardware_interface::HW_IF_POSITION, &jd.pos_state);
        }
        return si;
    }

    std::vector<hardware_interface::CommandInterface> UbtechServoSystem::export_command_interfaces() {
        std::vector<hardware_interface::CommandInterface> ci;
        ci.reserve(joints_.size());
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

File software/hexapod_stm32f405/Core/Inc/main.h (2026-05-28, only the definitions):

#define VM_EN_Pin GPIO_PIN_13
#define VM_EN_GPIO_Port GPIOC
#define AC_OK_Pin GPIO_PIN_14
#define AC_OK_GPIO_Port GPIOC
#define AC_OK_EXTI_IRQn EXTI15_10_IRQn
#define MPU_INT_Pin GPIO_PIN_15
#define MPU_INT_GPIO_Port GPIOC
#define MPU_INT_EXTI_IRQn EXTI15_10_IRQn
#define BC_IOUT_Pin GPIO_PIN_0
#define BC_IOUT_GPIO_Port GPIOC
#define TEMP1_ADC_Pin GPIO_PIN_1
#define TEMP1_ADC_GPIO_Port GPIOC
#define TEMP2_ADC_Pin GPIO_PIN_2
#define TEMP2_ADC_GPIO_Port GPIOC
#define SVM_ADC_Pin GPIO_PIN_3
#define SVM_ADC_GPIO_Port GPIOC
#define CS1_MPU_Pin GPIO_PIN_4
#define CS1_MPU_GPIO_Port GPIOA
#define FAN_EN_Pin GPIO_PIN_4
#define FAN_EN_GPIO_Port GPIOC
#define CV_ADC_Pin GPIO_PIN_5
#define CV_ADC_GPIO_Port GPIOC
#define HUSB238A_INT_Pin GPIO_PIN_2
#define HUSB238A_INT_GPIO_Port GPIOB
#define BUZZ_Pin GPIO_PIN_10
#define BUZZ_GPIO_Port GPIOA
#define WS2812_Pin GPIO_PIN_7
#define WS2812_GPIO_Port GPIOB

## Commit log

2025-11-20 first commit
    1. The initial completion of using STC8G to control SC8802 has been achieved;
    2.Init ros2 workspace using clion;
    3.Init stm32 ioc
2026-04-27 init stm32 project
2026-04-29 Ubtech servo ros2 control code generated by ai
    [hexapod_ros2_control.yaml]
2026-05-01 Replace mcu from stm32f401/411 to stm32f405rgt6 and complete the project preliminary configuration; Removed ydlidar_sdk submodules; Preliminarily completed the automatic generate and deploy of MicroR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
2026-05-03 upload model stl
    [21700_battery_holder.stl, 21700_battery_holder_cover.stl, body_bottom.stl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]
2026-05-03 update hexapod sensor interface
2026-05-04 Preliminarily completed the control of ubtech servo under ros2_control (not tested)
    [hexapod_ros2_control.yaml]
2026-05-04 add packages to test the impl of ubtech protocol
    [hexapod_test_ubtech_servo_node.yaml]
2026-05-06 upload step for urdf
2026-05-10 update step and upload SLDASM file
    [hexapod_for_urdf.SLDASM]
2026-05-13 rename ros2 workspace
    [hexapod_test_ubtech_servo_node.yaml]
2026-05-28 Preliminary completion of code on STM32F405
2026-06-03 add hexapod_description
    [coxa1_link.STL, coxa2_link.STL, coxa3_link.STL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]
2026-06-03 remove old sw files
    [hexapod_for_urdf.SLDASM, hexapod_for_urdf.stp]
2026-06-03 update models
    [21700_battery_holder.stl, 21700_battery_holder_bottom.stl, 21700_battery_holder_bottom_cover.stl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]
2026-06-03 update hexapod_description
    [hexapod_description.urdf]

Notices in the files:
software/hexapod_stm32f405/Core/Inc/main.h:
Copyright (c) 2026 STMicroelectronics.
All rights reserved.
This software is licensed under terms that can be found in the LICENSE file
